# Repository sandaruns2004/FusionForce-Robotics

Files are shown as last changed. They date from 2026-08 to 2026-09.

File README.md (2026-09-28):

# FusionForce RUNNER-4 — BREACH PROTOCOL
## EN2533 Autonomous Quadruped Competition Robot

> **MCU:** STM32F411CEU6 (Black Pill) | **Servos:** 15× MG90S | **Links:** L1=30mm L2=60mm L3=80mm
> **Gait:** Diagonal Trot | **Sensors:** 9-ch IR (ADC DMA) + 3× ToF + IMU + Colour

A fully autonomous 12-DOF 3D-printed quadruped robot built for the EN2533 BREACH PROTOCOL competition. All perception, mission logic, and real-time motor control run on a **single STM32F411CEU6** — no Raspberry Pi, no computer vision, no external processor.

---

## 🗂️ Repository Structure

```
FusionForce-Robotics/
├── docs/                   ← Engineering documentation (start here)
├── firmware/               ← STM32F411CEU6 bare-metal C firmware
├── Mechanical/             ← 3D print guides, assembly, calibration
├── Robot_Curriculum/       ← Learning path: L1 Fundamentals → L4 Sensors & Integration
├── Testing codes/          ← Arduino/STM32 test scripts per subsystem
├── 3D designs/             ← SolidWorks CAD assemblies
├── Task/                   ← Arena task specifications
└── Proposal/               ← Competition proposal documents
```

---

## ⚡ System at a Glance

```
         9× TCRT5000 IR Array    3× VL53L0X ToF    MPU6050    TCS34725
         (ADC1+DMA PA0-PA7,PB0)  (I2C2, XSHUT)    (I2C1)    (I2C1, arm tip)
                  │                    │               │           │
         ┌────────┴────────────────────┴───────────────┴───────────┴────────┐
         │              STM32F411CEU6 Black Pill (100MHz)                    │
         │  Mission HFSM (21 states) │ Trot Gait (600ms) │ IK Solver       │
         │  PD Line Follow │ PD Wall Follow │ Flash persistence │ UART debug│
         └───────────────────────────────┬────────────────────────────────── ┘
                                         │ I2C1 (400kHz)
                                   PCA9685 (0x40)
                                         │
              ┌──────────────┬───────────┴───────────┬──────────────┐
         CH0-CH11        CH12 Arm           CH13 Gripper      CH14 Gate
         12× MG90S       MG90S (0-160°)     MG90S (60-115°)  MG90S (0-90°)
         Leg Servos
```

---

## 🦾 Hardware Specification

| Parameter | Value |
|---|---|
| **MCU** | STM32F411CEU6 Black Pill — 100MHz ARM Cortex-M4F, FPU |
| **Servos** | 15× MG90S metal-gear, 2.2 kg·cm @ 6V |
| **Leg DOF** | 12 (3-DOF per leg × 4 legs) |
| **Coxa (L1)** | **30 mm** |
| **Femur (L2)** | **60 mm** |
| **Tibia (L3)** | **80 mm** |
| **Max reach** | L2+L3 = **140 mm** from coxa pivot |
| **Gait** | Diagonal trot — FL+BR / FR+BL, T=600ms, step=35mm |
| **Servo driver** | PCA9685, I2C1 (0x40), 50Hz, 500-2400µs |
| **Line array** | 9× TCRT5000, ADC1+DMA, 80mm wide, 10mm pitch |
| **ToF sensors** | 3× VL53L0X, I2C2 (0x30/0x31/0x32), XSHUT remapped |
| **IMU** | MPU6050, I2C1 (0x68), 100Hz, tilt safety watchdog |
| **Colour sensor** | TCS34725, I2C1 (0x29), arm tip mount, LED=PC0 |
| **Power** | 2S LiPo → 6V BEC (servo) + 3.3V logic, star ground |
| **Chassis** | PETG 3D-printed, body 160×120mm |

---

## 📚 Documentation

👉 **[Full Engineering Docs →](docs/README.md)**

| Doc | Description |
|-----|---|
| [Technical Blueprint](docs/TECHNICAL_BLUEPRINT.md) | Complete system manual — start here |
| [Hardware Architecture](docs/HARDWARE_ARCHITECTURE.md) | Compute, sensor, actuator block diagram |
| [Pinout & Connections](docs/PINOUT_AND_CONNECTIONS.md) | Authoritative STM32 pin assignment table |
| [Locomotion & Kinematics](docs/LOCOMOTION_AND_KINEMATICS.md) | IK derivation, trot gait math, PD controllers |
| [Embedded State Machine](docs/EMBEDDED_STATE_MACHINE.md) | 21-state HFSM — all 4 competition tasks |
| [Sensor Perception](docs/SENSOR_PERCEPTION.md) | 9-ch IR array + TCS34725 algorithms |
| [Software Architecture](docs/SOFTWARE_ARCHITECTURE.md) | Firmware structure, 50Hz loop |
| [Power Architecture](docs/POWER_ARCHITECTURE.md) | Dual-rail power, star ground, protection |
| [Mechanical Design](docs/MECHANICAL_DESIGN.md) | Chassis, leg assembly, arm, CoM analysis |
| [Troubleshooting Guide](docs/TROUBLESHOOTING.md) | UART debug commands, common fixes |
| [Master Checklist](docs/MASTER_IMPLEMENTATION_CHECKLIST.md) | Step-by-step build + test checklist |

---

## 🎓 Team Learning Curriculum

New team members: complete the curriculum before touching firmware code.

👉 **[Master Robotics Curriculum →](Robot_Curriculum/README.md)**

| Level | Topics | Est. Time |
|---|---|---|
| [Level 1 — Fundamentals](Robot_Curriculum/Level_1_Fundamentals/README.md) | C, Electronics, Git, CubeMX setup | 2–3 weeks |
| [Level 2 — STM32](Robot_Curriculum/Level_2_STM32/README.md) | HAL, I2C, ADC DMA, PCA9685, Timers | 2–3 weeks |
| [Level 3 — Robotics Core](Robot_Curriculum/Level_3_Robotics/README.md) | IK, trot gait, PD control, HFSM | 2–3 weeks |
| [Level 4 — Sensors & Integration](Robot_Curriculum/Level_4_Sensors_and_Gait/README.md) | Full mission, all sensors, competition run | 1–2 weeks |

---

## 🔧 Mechanical Assembly

👉 **[Mechanical Assembly Workflow →](Mechanical/README.md)**

| Module | Description |
|---|---|
| [01 Chassis Design](Mechanical/01_chassis_design/README.md) | PETG print specs, CoG planning |
| [02 Leg Assembly](Mechanical/02_leg_assembly/README.md) | 12× MG90S, L1/L2/L3 links, channel map |
| [03 Gripper & Gate](Mechanical/03_gripper_and_bumper/README.md) | CH12 arm, CH13 gripper, CH14 gate |
| [04 Electronics Mounting](Mechanical/04_electronics_mounting/README.md) | STM32, PCA9685, all sensor placements |
| [05 Power Distribution](Mechanical/05_power_distribution/README.md) | 6V servo rail, 3.3V logic, star ground |
| [06 Calibration & Zeroing](Mechanical/06_calibration_and_zeroing/README.md) | 15-servo zeroing, UART calibration |
| [07 Maintenance & Repair](Mechanical/07_maintenance_and_repair/README.md) | Pre-run checklist, failure diagnosis |

---

## 🏁 Competition Tasks

| Task | Description | Primary Sensors |
|---|---|---|
| **Task 1** | Follow white line → find ball → colour ID → grab & store | IR array (line) + ToF (proximity) + TCS34725 (colour) |
| **Task 2** | Navigate corridor with gaps | ToF ×3 (wall-follow PD) |
| **Task 3** | Detect and push obstacle | ToF front (obstacle) + IMU (tilt safety) |
| **Task 4** | Follow line → junction → colour-match zone → release ball | IR array + TCS34725 (floor zone) |

---

*Repository status: Active development. All documentation is current as of hardware confirmation: L1=30mm, L2=60mm, L3=80mm, 15× MG90S, STM32F411CEU6.*

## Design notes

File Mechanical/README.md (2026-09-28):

# Mechanical Assembly & Hardware Workflow
## RUNNER-4 | 12-DOF Quadruped | EN2533 BREACH PROTOCOL

> **MCU:** STM32F411CEU6 (Black Pill) | **Servos:** 12x MG90S legs + 3x MG90S mechanisms = **15 total**
> **Links:** Coxa = 30 mm | Femur = 60 mm | Tibia = 80 mm | **Power:** 6V switching BEC ≥5A

## Assembly Workflow

```mermaid
flowchart TD
    classDef phase fill:#1a3a5c,stroke:#2e86de,color:#fff,stroke-width:2px;
    classDef critical fill:#7b1e1e,stroke:#e74c3c,color:#fff,stroke-width:2px;

    A[01. Chassis Design\n3D Print + Materials + CoG]:::phase
    B[02. Leg Assembly\n12x MG90S + 3-DOF per leg]:::phase
    C[03. Gripper + Gate\nCH12 Arm + CH13 Grip + CH14 Gate]:::phase
    D[04. Electronics Mounting\nSTM32 + PCA9685 + Sensors]:::phase
    E[05. Power Distribution\n6V BEC + 3.3V Logic Rail]:::phase
    F[06. Servo Zeroing\n90-deg Mechanical Calibration]:::critical
    G[07. Maintenance\nPre-Run Checklists]:::phase

    A --> B
    B --> C
    C --> D
    D --> E
    E --> F
    F --> G
```

## Module Summary

| # | Module | Key Hardware | Status |
|---|---|---|---|
| 01 | [Chassis Design](./01_chassis_design/README.md) | PETG body, base plate, top plate | Design phase |
| 02 | [Leg Assembly](./02_leg_assembly/README.md) | 12x MG90S, L1=30 L2=60 L3=80mm | Assembly phase |
| 03 | [Gripper & Gate](./03_gripper_and_bumper/README.md) | CH12 arm, CH13 gripper, CH14 gate | Assembly phase |
| 04 | [Electronics Mounting](./04_electronics_mounting/README.md) | STM32, PCA9685, IMU, ToF, IR array | Wiring phase |
| 05 | [Power Distribution](./05_power_distribution/README.md) | Switching BEC 6V, 3.3V logic | Wiring phase |
| 06 | [Calibration & Zeroing](./06_calibration_and_zeroing/README.md) | PCA9685 UART cal, offset array | **Critical step** |
| 07 | [Maintenance & Repair](./07_maintenance_and_repair/README.md) | Pre-run checklist, common failures | Ongoing |

## Hardware Bill of Materials (Mechanical)

| Item | Qty | Spec | Notes |
|---|-----|---|---|
| MG90S Metal Gear Servo | 15 | 2.2 kg.cm @ 6V | 12 legs + 3 arm/grip/gate |
| PETG Filament | ~400g | 1.75mm, black | Body plates + brackets |
| M3 Socket Head Screws | 80 | 8mm, 12mm, 16mm | All structural joints |
| M3 Locknuts (nylon) | 60 | DIN985 | Vibration-proof joints |
| M2.5 Standoffs | 20 | Brass, 10mm | PCB mounting |
| Brass Heat-set Inserts | 40 | M3 | PETG structural holes |
| Radial Bearings | 12 | 3x8x3mm MR83ZZ | Opposite side of coxa servo horns |
| Rubber Feet | 4 | 10mm dia silicone | Tibia tips, prevents slipping |
| Servo Extension Wire | 2m | 3-pin 26AWG | Leg routing |

---
🔙 **[Back to Main Repository README](../README.md)**

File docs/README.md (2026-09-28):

# FusionForce Engineering Documentation
## RUNNER-4 | EN2533 BREACH PROTOCOL | STM32F411CEU6

Authoritative technical documentation, architectural blueprints, and tracking checklists.
**No Raspberry Pi. No Computer Vision. All perception is sensor-based (IR array, ToF, colour sensor, IMU).**

## Core Planning & Tracking

| Document | Purpose |
|---|---|
| **[Technical Blueprint](./TECHNICAL_BLUEPRINT.md)** | Comprehensive system manual — Start Here |
| **[Technical Proposal](./TECHNICAL_PROPOSAL.md)** | Executive engineering proposal |
| **[Execution Report](./EXECUTION_REPORT.md)** | Project management tracker |
| **[Master Implementation Checklist](./MASTER_IMPLEMENTATION_CHECKLIST.md)** | Step-by-step implementation guide |
| **[Risk Register (FMEA)](./RISK_REGISTER.md)** | Risk analysis and mitigation |
| **[Requirements](./REQUIREMENTS.md)** | System requirements and constraints |

## Technical Architecture

| Document | Purpose |
|---|---|
| **[System Overview](./SYSTEM_OVERVIEW.md)** | Single-domain STM32 architecture — why no Raspberry Pi |
| **[Hardware Architecture](./HARDWARE_ARCHITECTURE.md)** | Compute + sensor + actuator layers, block diagram |
| **[STM32 Architecture](./STM32_ARCHITECTURE.md)** | STM32F411CEU6 peripherals, CubeMX config |
| **[Software Architecture](./SOFTWARE_ARCHITECTURE.md)** | 50Hz loop, firmware directory structure |
| **[Power Architecture](./POWER_ARCHITECTURE.md)** | 6V servo rail, 3.3V logic rail, star ground |
| **[Locomotion & Kinematics](./LOCOMOTION_AND_KINEMATICS.md)** | IK solver (L1=30 L2=60 L3=80mm), trot gait, PD controllers |
| **[Mechanical Design](./MECHANICAL_DESIGN.md)** | PETG chassis, leg assembly, arm+gripper, line array bracket |
| **[Embedded State Machine](./EMBEDDED_STATE_MACHINE.md)** | 21-state HFSM, all 4 tasks, transition tables |

## Sensors & Perception

| Document | Purpose |
|---|---|
| **[Sensor Perception](./SENSOR_PERCEPTION.md)** | 9-ch IR array (ADC DMA) + TCS34725 algorithms |
| **[Pinout and Connections](./PINOUT_AND_CONNECTIONS.md)** | Complete STM32 pin assignments (authoritative) |

## Safety & Maintenance

| Document | Purpose |
|---|---|
| **[Safety and Failure Modes](./SAFETY_AND_FAILURE_MODES.md)** | Failsafes, hardware protection, SAFE_STOP |
| **[Troubleshooting Guide](./TROUBLESHOOTING.md)** | Common issues, UART debug commands, fixes |

## Quick Reference

### Hardware at a Glance
```
MCU:    STM32F411CEU6 Black Pill — 100MHz, 512KB Flash, 128KB RAM
Servos: 15× MG90S | CH0-11 legs | CH12 arm | CH13 gripper | CH14 gate
Links:  L1 (Coxa)=30mm | L2 (Femur)=60mm | L3 (Tibia)=80mm
Gait:   Trot | T=600ms | Step height=35mm | Vx_max=100mm/s
Power:  6V BEC (servo) | 3.3V logic | 2S LiPo | Star ground
```

### I2C Bus Map
```
I2C1 (PB6/PB7): PCA9685@0x40 | MPU6050@0x68 | TCS34725@0x29
I2C2 (PB10/PB3): VL53L0X Front@0x30 | Left@0x31 | Right@0x32
```

### ADC Line Array
```
ADC1 + DMA1 circular | S1-S8: PA0-PA7 | S9: PB0
9× TCRT5000 | 80mm wide | 10mm pitch | 16× oversample | 5mm from floor
Centroid range: 0-8 | error = centroid - 4.0
```

### Arm Positions
```
CH12 HOME  = 90°  (tick 307) — vertical, safe for walking
CH12 MODE_A = 0°  (tick 102) — horizontal forward, ball at pedestal
CH12 MODE_B = 160° (tick 450) — angled down to floor, zone ID
CH13 OPEN   = 60°  (tick 184) — gripper open (40mm ball)
CH13 CLOSE  = 115° (tick 286) — gripper gripping
CH14 LOCKED = 0°   (tick 102) — gate closed
CH14 OPEN   = 90°  (tick 307) — gate open (ball exits)
```

---
🔙 **[Back to Main Repository README](../README.md)**

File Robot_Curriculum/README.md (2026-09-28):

# FusionForce Master Robotics Curriculum
## RUNNER-4 | EN2533 BREACH PROTOCOL | STM32F411CEU6

Progress through these 4 levels to build full competency for autonomous quadruped development.
No computer vision — all perception is sensor-based (IR array, ToF, colour sensor, IMU).

## Curriculum Path

```mermaid
flowchart LR
    L1["Level 1\nFundamentals\nC + Electronics\nGit + Linux"]
    L2["Level 2\nSTM32 Firmware\nHAL + I2C + ADC\nDMA + Timers"]
    L3["Level 3\nRobotics Core\nIK + Gait\nPID + State Machine"]
    L4["Level 4\nSensors & Gait\nFull Integration\nCompetition Ready"]
    L1 --> L2 --> L3 --> L4
```

## Modules

| Level | Module | Topics | Time Estimate |
|---|---|---|---|
| [Level 1](./Level_1_Fundamentals/README.md) | Fundamentals | C, Electronics, Git, STM32 setup | 2–3 weeks |
| [Level 2](./Level_2_STM32/README.md) | STM32 Firmware | HAL, I2C, ADC DMA, PCA9685, Timers | 2–3 weeks |
| [Level 3](./Level_3_Robotics/README.md) | Robotics Core | IK solver, trot gait, PD control | 2–3 weeks |
| [Level 4](./Level_4_Sensors_and_Gait/README.md) | Sensors & Integration | All sensors, HFSM, full mission | 1–2 weeks |

## What This Curriculum Does NOT Cover
- Computer vision / OpenCV — all RUNNER-4 perception uses hardware sensors
- Raspberry Pi — all logic runs on STM32F411CEU6
- ROS / ROS2 — bare-metal HAL only

---
🔙 **[Back to Main Repository README](../README.md)**

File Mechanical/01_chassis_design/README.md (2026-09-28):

# 01 Chassis Design
## RUNNER-4 | Body Frame and 3D Printing Guide

## Objective
Design and 3D-print a rigid, perfectly symmetrical chassis that keeps the Center of Gravity (CoG) within the quadruped's support polygon at all times.

## Body Dimensions

```
Top view:

  FL coxa mount ----+--------+---- FR coxa mount
                    |        |
                    | BODY   |
                    | 160mm  |
                    | x      |
                    | 120mm  |
                    |        |
  BL coxa mount ----+--------+---- BR coxa mount

  Body half-length (front/rear to centre): 80 mm
  Body half-width  (left/right to centre): 60 mm
  CoG target: geometric centre of body plate
```

## 3D Printing Specifications

| Part | Material | Infill | Perimeters | Notes |
|---|---|---|---|---|
| Base plate (bottom deck) | PETG | 40% Gyroid | 4 | Battery + BEC mounting surface |
| Top plate (upper deck) | PETG | 30% Gyroid | 4 | STM32 + PCA9685 mounting surface |
| Coxa servo bracket (x4) | PETG | 100% | 5 | Highest stress — no PLA |
| Femur link (x4) | PETG | 50% Gyroid | 4 | |
| Tibia link (x4) | PETG | 50% Gyroid | 4 | Rubber foot socket at tip |
| Arm mount bracket | PETG | 100% | 4 | CH12 arm pitch servo mount |
| Gripper fingers (x2) | PETG/TPU | 80% | 3 | TPU preferred — better grip |
| Gate plate | PETG | 60% | 3 | CH14 gate servo horn mount |

> **Do NOT use PLA** for structural parts. PLA deforms under continuous servo heat (>55°C body temperature) and shatters on arena collision impacts.

## Slicer Settings (Cura / PrusaSlicer)

```
Layer height:     0.2mm standard | 0.15mm for servo brackets
Print speed:      40mm/s perimeters | 60mm/s infill
Bed temp:         80°C (PETG)
Nozzle temp:      240°C (PETG)
Supports:         Only for overhangs > 50°
Cooling:          Moderate (PETG warps with aggressive cooling)
```

## Center of Gravity Planning

The quadruped's support polygon during trot gait is the diagonal between FL+BR or FR+BL. The CoG must stay inside this triangle at all times:

```
  CoG position targets:
  - Battery (heaviest, ~200g): centre of bottom deck, LOW
  - PCA9685 + STM32: middle deck, centred front-back
  - Sensors (ToF/IMU): front of top deck, symmetric

  AVOID: mounting heavy components at back edge
  (shifts CoG backward -> front legs lose traction on acceleration)
```

## Assembly Tasks

1. Export all STLs from the `3D designs/` folder (SolidWorks assemblies)
2. Slice with PETG profiles above
3. Install M3 brass heat-set inserts into all screw holes (use soldering iron tip at 200°C)
4. Print 4x coxa brackets — test-fit servo before installing inserts
5. Assemble base plate + standoffs for middle deck
6. Assemble top deck plate

## Files Location
- CAD sources: [`3D designs/`](../3D%20designs/)
- Reference assembly: `3D designs/` SolidWorks files

---
🔙 **[Back to Mechanical](../README.md)**

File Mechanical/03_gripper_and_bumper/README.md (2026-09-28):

# 03 Gripper & Gate Mechanism
## RUNNER-4 | CH12 Arm Pitch | CH13 Gripper | CH14 Gate

## Objective
Build the three mechanism servos that handle ball retrieval (Task 1), storage, and ball release into the colour-sorted zone (Task 4).

## Mechanism Overview

```
  SIDE VIEW OF ROBOT:

  HOME (CH12 = 90°):           ARM pointing UP — safe for travel/walk

  MODE_A (CH12 = 0°):          ARM horizontal FORWARD
                                Sensor at ball height (~5cm above pedestal)
                                Use for: Task 1 ball approach + colour ID

  MODE_B (CH12 = 160°):        ARM angled DOWN to floor
                                Sensor 2cm above floor zone
                                Use for: Task 4 zone colour identification

  Gripper CH13:
    OPEN  = 60°  → fingers wider than 40mm ball diameter
    CLOSE = 115° → fingers grip ball firmly

  Gate CH14 (belly storage door):
    LOCKED = 0°  → plate closed, retains ball inside body
    OPEN   = 90° → plate rotates, ball rolls out into zone
```

## PCA9685 Channels — Mechanism Servos

| CH | Function | Servo | HOME tick | Key positions |
|----|---|---|---|---|
| 12 | Arm pitch | MG90S | 307 (90°) | 102=MODE_A(0°), 450=MODE_B(160°), 380=STORE(135°) |
| 13 | Gripper | MG90S | 184 (60°) | 184=OPEN(60°), 286=CLOSE(115°) |
| 14 | Gate | MG90S | 102 (0°) | 102=LOCKED(0°), 307=OPEN(90°) |

## Torque Budget

| Servo | Load | Required | MG90S @ 6V | Margin |
|---|---|---|---|---|
| CH12 Arm | 40mm ball at 65mm arm | 2.35 kg·cm | 2.2 kg·cm | **0.94x — marginal** |
| CH13 Gripper | Ball grip force | 1.02 kg·cm | 2.2 kg·cm | 2.15x OK |
| CH14 Gate | Spring-loaded door | 0.76 kg·cm | 2.2 kg·cm | 2.89x OK |

> **⚠️ CH12 Arm Warning:** Torque margin is below 1.0x at maximum arm extension.
> Fix options: (A) Shorten arm link to 55mm, (B) Upgrade CH12 to MG996R (10 kg·cm), (C) Add counterweight.

## Hardware Required

| Part | Qty | Notes |
|---|-----|---|
| MG90S metal-gear servo | 3 | CH12, CH13, CH14 |
| Arm link (PETG, 100% infill) | 1 | 65mm long, servo horn mount one end, TCS34725 mount other end |
| Gripper fingers (PETG or TPU) | 2 | Line with rubber band or foam tape for friction |
| Gate plate (PETG, 60% infill) | 1 | Hinged to belly of chassis |
| M3×8 screws | 8 | Servo mounting |
| M2 screws | 4 | TCS34725 sensor mount on arm tip |

## TCS34725 Colour Sensor on Arm

The TCS34725 colour sensor mounts at the **tip of the arm link**:
- ARM_MODE_A (0°): sensor faces ball at pedestal height → identifies ball colour
- ARM_MODE_B (160°): sensor faces floor zone → identifies floor zone colour for Task 4

```
  Arm tip wiring:
  TCS34725 -> I2C1 bus (SDA=PB7, SCL=PB6) shared with MPU6050
  LED control -> PC0 (GPIO output, HIGH = white LED ON for measurement)
  I2C address: 0x29
```

## Sequence per Task

### Task 1 — Ball Retrieval
```
1. SM: T1_LINE_FOLLOW  -> ARM_HOME,  GRIPPER_OPEN,  GATE_LOCKED
2. SM: T1_BALL_APPROACH-> ARM_MODE_A, GRIPPER_OPEN,  GATE_LOCKED  (800ms)
3. SM: T1_COLOR_ID     -> ARM_MODE_A, GRIPPER_OPEN,  GATE_LOCKED  (3 stable reads)
4. SM: T1_BALL_GRAB    -> ARM_MODE_A, GRIPPER_CLOSE, GATE_LOCKED  (1200ms)
5. SM: T1_STORE        -> ARM_HOME,   GRIPPER_CLOSE, GATE_LOCKED  (1000ms)
```

### Task 4 — Ball Release
```
6. SM: T4_JUNCTION     -> ARM_MODE_B, GRIPPER_CLOSE, GATE_LOCKED  (floor zone ID)
7. SM: T4_BALL_RELEASE -> ARM_HOME,   GRIPPER_OPEN,  GATE_OPEN    (1500ms, ball exits)
```

## Assembly Steps

1. Mount CH12 arm servo to chassis front face, servo shaft pointing UP
2. Attach arm link to servo horn (do NOT attach horn until Module 06 zeroing)
3. Mount TCS34725 PCB to arm tip with M2 screws, LED facing outward
4. Route TCS34725 I2C cable along arm, secure with small zip ties at 10mm intervals — must not snag during arm movement
5. Mount CH13 gripper servo to arm link midpoint
6. Attach finger assembly to CH13 servo horn
7. Line finger interior with 2mm foam tape or rubber band strips
8. Mount gate plate hinge to belly chassis with M3×16 bolts
9. Attach CH14 gate servo to chassis side, servo horn attached to gate plate
10. Verify gate: at 0° plate fully closes, at 90° plate swings clear (ball can exit)

## Debugging

| Problem | Cause | Fix |
|---|---|-----|
| Arm droops under ball weight | CH12 margin too low | Shorten arm link or upgrade to MG996R |
| Gripper can't hold ball | Fingers too smooth | Add rubber band / foam tape lining |
| Gate doesn't open fully | Servo horn angle wrong | Re-zero CH14 at Module 06 |
| Colour reads wrong at MODE_A | LED (PC0) not powered | Verify PC0 GPIO HIGH before reading |
| Arm cable snags during walk | Cable too short/loose | Add 50mm slack loop, zip-tie to chassis |

---
🔙 **[Back to Mechanical](../README.md)**

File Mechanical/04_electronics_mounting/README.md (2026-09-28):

# 04 Electronics Mounting
## RUNNER-4 | STM32F411CEU6 + PCA9685 + Sensor Suite

## Objective
Securely mount all electronics to withstand continuous walking vibrations and ensure correct sensor field-of-view (FoV) placement.

## Electronics Stack Layout

```
  TOP DECK (upper plate):
  ┌─────────────────────────────────────────┐
  │  STM32F411CEU6 Black Pill               │  <- Screwed into M2.5 brass standoffs
  │  (on perfboard/custom PCB)              │
  │                                         │
  │  PCA9685 PWM Driver (0x40)              │  <- Screwed into M2.5 standoffs
  │  [4.7kΩ pull-ups I2C1 SDA/SCL]         │
  └─────────────────────────────────────────┘

  SENSOR POSITIONS (top deck, front face):
  ┌─────────────────────────────────────────┐
  │  [VL53L0X LEFT]  [VL53L0X FRONT]  [VL53L0X RIGHT]  │
  │  addr 0x31        addr 0x30         addr 0x32       │
  │  XSHUT PB13       XSHUT PB12       XSHUT PB14      │
  │                                                     │
  │  [MPU6050 IMU] — mount at geometric centre, flat    │
  │  addr 0x68  I2C1                                    │
  └─────────────────────────────────────────┘

  BOTTOM DECK (base plate):
  ┌─────────────────────────────────────────┐
  │  LiPo Battery 2S/3S        (Velcro strap, centre)  │
  │  Switching BEC 6V ≥5A      (Zip-tie side mount)    │
  │  3.3V LDO/SMPS             (Side mount)            │
  └─────────────────────────────────────────┘

  FRONT EDGE (IR sensor bar):
  ┌─────────────────────────────────────────┐
  │  9x TCRT5000 IR sensors (S1-S9)         │
  │  PA0-PA7, PB0 → ADC1 DMA               │
  │  Mounted 5mm above arena floor          │
  │  80mm total width, 10mm pitch           │
  └─────────────────────────────────────────┘
```

## Component List

| Component | Mount Location | Mount Method | Notes |
|---|---|---|---|
| STM32F411CEU6 | Top deck | M2.5 nylon standoffs + rubber washers | Vibration isolation |
| PCA9685 | Top deck | M2.5 brass standoffs | Keep away from IR sensors |
| MPU6050 IMU | Top deck, geometric centre | M2.5 standoffs, perfectly flat | ±1° tilt tolerance |
| TCS34725 Colour Sensor | Arm tip (CH12) | M2 screws | Moves with arm |
| VL53L0X Front | Front edge, centre | M2 mount, forward-facing | 0° horizontal |
| VL53L0X Left | Left edge | M2 mount, 90° left-facing | Exactly perpendicular |
| VL53L0X Right | Right edge | M2 mount, 90° right-facing | Exactly perpendicular |
| 9x TCRT5000 IR | Underside front bar | Custom PCB / perfboard | 5mm from floor |
| Switching BEC | Bottom deck | Zip-tie | 6V servo power |
| LiPo Battery | Bottom deck centre | Velcro strap | CoG alignment critical |

## I2C Bus Wiring

```
I2C1 (SDA=PB7, SCL=PB6) — 4.7kΩ pull-ups to 3.3V:
  PCA9685      @ 0x40   (PWM driver, 15 servos)
  MPU6050      @ 0x68   (IMU)
  TCS34725     @ 0x29   (colour sensor on arm)

I2C2 (SDA=PB3, SCL=PB10) — 4.7kΩ pull-ups to 3.3V:
  VL53L0X Front @ 0x30  (remapped from 0x29 via XSHUT PB12)
  VL53L0X Left  @ 0x31  (remapped from 0x29 via XSHUT PB13)
  VL53L0X Right @ 0x32  (remapped from 0x29 via XSHUT PB14)
```

> **Why separate I2C buses?** VL53L0X readings take ~30ms each. If on I2C1 with PCA9685, ToF measurements would block servo updates. I2C2 isolates them completely.

## ADC / DMA Wiring

```
ADC1 + DMA1 (circular scan, 16x oversampling):
  S1 PA0   S2 PA1   S3 PA2   S4 PA3   S5 PA4
  S6 PA5   S7 PA6   S8 PA7   S9 PB0

  Pull-up resistors: 10kΩ to 3.3V for each TCRT5000 emitter
  DMA buffer: 9 × 16 = 144 uint32_t words
```

## GPIO Assignments

| Pin | Function | Direction | Notes |
|-----|---|---|---|
| PB12 | VL53L0X FRONT XSHUT | Output PP | LOW=reset, HIGH=active |
| PB13 | VL53L0X LEFT XSHUT | Output PP | |
| PB14 | VL53L0X RIGHT XSHUT | Output PP | |
| PC0 | TCS34725 LED enable | Output PP | HIGH=LED ON |
| PC13 | Start button | Input PU | Active LOW (press to start) |
| PA9 | USART1 TX | Alt AF7 | Debug 115200 baud |
| PA10 | USART1 RX | Alt AF7 | |

## Sensor Placement Rules

### MPU6050 IMU (CRITICAL)
- Must be at **exact geometric centre** of robot body
- Must be **perfectly horizontal** (±1° tolerance)
- If tilted, the complementary filter will report false pitch/roll and the state machine will trigger `IMU_TIP_THRESHOLD` incorrectly
- Mount with rubber washers to dampen servo vibration from IMU accelerometer

### VL53L0X ToF Sensors
- Front sensor: pointing **dead ahead**, 0° from robot X-axis
- Left sensor: pointing **exactly 90° left**, perpendicular to robot Y-axis
- Right sensor: pointing **exactly 90° right**
- No chassis parts in the 25° cone FoV — check by shining a torch through the FoV
- Sensors mounted at **same height** as corridor wall mid-height (approx. 40mm from floor)

### IR Line Array (9x TCRT5000)
- Mounted **5mm above arena floor** — optimal TCRT5000 sensing distance
- Total width: 80mm, pitch: 10mm between sensors (S1-S9 left to right)
- S5 (PA4, centre) must align with robot X-axis centreline
- Sensor PCB must be rigid — flex PCB causes variable readings

## Vibration Mitigation

- Use **nylon M2.5 standoffs** + rubber washers for all PCB mounts
- Apply **hot glue** or cable tie to all I2C/power connector joints (arena vibrations loosen DuPont connectors)
- Route servo cables along structural members, not free-hanging

---
🔙 **[Back to Mechanical](../README.md)**

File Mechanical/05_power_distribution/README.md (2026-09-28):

# 05 Power Distribution
## RUNNER-4 | Dual-Rail Power System | 6V Servo + 3.3V Logic

## Objective
Route high-current servo power and low-noise logic power safely, avoiding brownouts, ground loops, and servo damage to the STM32.

## The Two Power Rails

```
  LiPo Battery (2S=7.4V or 3S=11.1V)
       |
       +---[Kill Switch 15A]---+
                               |
               +---------------+---------------+
               |                               |
   [Switching BEC ≥5A]               [LDO/SMPS 3.3V]
   Output: 6.0V                      Output: 3.3V
               |                               |
   +-----------+----------+         +----------+-----------+
   |           |          |         |          |           |
  PCA9685   Servo V+   Servo V+   STM32    PCA9685   Sensors
  (servo)   CH0-CH11  CH12-14    VCC       (logic)  (I2C/ADC)

  GND: ALL above share one thick common GND wire (star ground)
```

## Power Consumption Analysis

| Component | Rail | Typical | Peak (stall) |
|---|---|---|---|
| STM32F411CEU6 | 3.3V | 30 mA | 50 mA |
| PCA9685 logic | 3.3V | 10 mA | 15 mA |
| MPU6050 | 3.3V | 3.9 mA | 4 mA |
| TCS34725 + LED | 3.3V | 11 mA | 11 mA |
| 3× VL53L0X | 3.3V | 30 mA | 30 mA |
| 9× TCRT5000 IR | 3.3V | 81 mA | 81 mA |
| **3.3V Total** | | **~166 mA** | ~191 mA |
| 12× MG90S legs | 6V | 1200–2400 mA | 8400 mA |
| 3× MG90S arm/grip/gate | 6V | 200–400 mA | 2100 mA |
| **6V Servo Total** | | **1.4–2.8 A** | **~10.5 A stall** |

> **BEC Selection:** Must be switching type, ≥5A continuous, ≥10A peak. Linear BEC overheats and causes brownout at high current. Recommended: 5A or 8A SBEC module.

## Wiring Steps

### Step 1: Battery and Kill Switch
```
1. Solder XT60 male connector to LiPo leads
2. Splice 15A latching toggle switch onto RED (positive) lead
   - Switch in series, NOT across the battery
3. Add 10A automotive blade fuse inline to servo BEC output
```

### Step 2: 6V Servo Rail (BEC)
```
1. Connect BEC input (raw) to battery positive rail
2. Set BEC output to 6.0V ± 0.1V (measure with multimeter under load)
3. Connect BEC output (+6V) to PCA9685 V+ terminal block
4. DO NOT connect BEC output to PCA9685 VCC pin (that is logic power only)
5. All 15 servo red wires connect to the same +6V rail
```

### Step 3: 3.3V Logic Rail
```
1. Connect LDO/SMPS input to battery positive rail
2. Set output to 3.3V ± 0.05V
3. Connect to STM32 3V3 pin
4. Connect to PCA9685 VCC (logic)
5. Connect to all sensor VCC pins (MPU6050, VL53L0X ×3, TCS34725)
   NOTE: TCRT5000 IR sensors — use 3.3V with 10kΩ pull-up resistors
```

### Step 4: Star Ground
```
ALL of the following GND wires must join at ONE point:
  - BEC output GND
  - LDO/SMPS output GND
  - STM32 GND pin
  - PCA9685 GND (both logic GND and servo GND rails)
  - All sensor GND pins
  - LiPo battery negative

Use a thick (18AWG) wire from LiPo negative to this star point.
From star point use thinner wires to individual components.
This eliminates ground loops that cause servo jitter and IMU noise.
```

## Pull-up Resistors (I2C)

```
I2C1 (PB6 SCL, PB7 SDA): 4.7kΩ to 3.3V (×2 resistors)
I2C2 (PB10 SCL, PB3 SDA): 4.7kΩ to 3.3V (×2 resistors)
Total: 4 resistors (4.7kΩ 0603 or through-hole)
```

> **Never omit pull-ups.** Without them, I2C signals float and all I2C devices (PCA9685, MPU6050, VL53L0X, TCS34725) will fail intermittently.

## Safety Features

| Protection | Component | Spec | Purpose |
|---|---|---|---|
| Main fuse | Automotive blade | 15A | Protects battery leads |
| Servo fuse | Automotive blade | 10A | Protects BEC output |
| Kill switch | Latching toggle | 15A | Emergency off |
| Decoupling caps | Ceramic 100nF | X7R | One per sensor/IC for noise |
| Servo rail cap | Electrolytic 470µF | 16V | Absorbs servo current spikes |

## Voltage Checks (before first power-on)

```
[ ] Battery voltage > 7.4V (2S) or > 11.1V (3S)
[ ] BEC output = 6.0V ± 0.1V  (under servo load)
[ ] 3.3V rail  = 3.30V ± 0.05V
[ ] All sensor VCC pins read 3.3V
[ ] PCA9685 V+  reads 6.0V
[ ] PCA9685 VCC reads 3.3V
[ ] All GND connections continuity-checked
[ ] No short between 6V rail and 3.3V rail
```

## Common Mistakes

| Mistake | Consequence | Fix |
|---|---|-----|
| Servo wire into STM32 5V/3.3V pin | STM32 burned instantly | Use BEC output only |
| Linear BEC at high servo current | Overheating, brownout | Use switching BEC only |
| Missing star ground | Ground loops, servo jitter, IMU noise | Wire all GNDs together |
| Missing I2C pull-ups | I2C bus failure, all sensors fail | Add 4.7kΩ per bus |
| Missing servo rail cap | Servo spike brownouts | Add 470µF on servo rail |

---
🔙 **[Back to Mechanical](../README.md)**

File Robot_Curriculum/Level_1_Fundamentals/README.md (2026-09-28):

# Level 1 — Fundamentals
## Prerequisites for RUNNER-4 Firmware Development

## Why This Level Matters
Every higher-level skill (IK math, gait engines, sensor drivers) depends on these fundamentals. Gaps here cause mysterious bugs later. Invest the time.

## Topics

### 1. C Programming for Embedded Systems
| Topic | Key Concepts | Application on RUNNER-4 |
|---|---|---|
| Pointers & memory | `*ptr`, `&addr`, arrays as pointers | IK solver passes `FootTarget_t *foot` |
| Structs | `typedef struct { float x,y,z; } FootTarget_t` | All data passed as structs |
| Fixed-width types | `uint8_t`, `uint16_t`, `int16_t` | ADC buffers, I2C register maps |
| Bitwise operations | `&`, `\|`, `<<`, `>>` | PCA9685 register config, ADC status |
| `volatile` keyword | Prevents compiler optimisation of ISR variables | `volatile uint8_t update_flag` in main loop |
| `const` arrays | Read-only flash data | `IK_NeutralStance[4]`, calibration tables |
| Math.h | `atan2f()`, `sqrtf()`, `sinf()`, `acosf()` | Entire IK + gait engine |

### 2. Electronics Fundamentals
| Topic | Key Concepts | Application |
|---|---|---|
| Ohm's Law | V=IR, power P=VI | BEC current sizing (P=6V×10A=60W) |
| Pull-up resistors | R to VCC, open-drain signals | I2C bus: 4.7kΩ to 3.3V |
| Decoupling capacitors | 100nF ceramic per IC | Servo noise rejection |
| PWM signals | Frequency, duty cycle, pulse width | Servo control: 50Hz, 500–2400µs |
| I2C protocol | SDA/SCL, address, ACK/NACK | All sensors + PCA9685 |
| ADC conversion | 12-bit, reference voltage, sampling time | TCRT5000 line array |
| DMA transfers | Memory-to-peripheral without CPU | ADC1 circular DMA for IR array |

### 3. Git & Version Control
```bash
# Essential commands for this project:
git clone <repo>
git checkout -b feature/gait-engine    # Always branch for new features
git add firmware/Motion/gait_engine.c
git commit -m "feat: add trot gait diagonal phase"
git push origin feature/gait-engine
git pull origin main                   # Before starting new work
```

### 4. STM32CubeMX Setup
Learn to configure:
- **Clock**: HSE 25MHz → PLL → 100MHz SYSCLK
- **I2C1**: PB6(SCL), PB7(SDA), 400kHz, interrupt mode
- **I2C2**: PB10(SCL), PB3(SDA), 400kHz
- **ADC1**: IN0-8 (PA0-PA7, PB0), DMA1 Stream0 Ch0, circular
- **TIM2**: 20ms period (50Hz) → `update_flag` interrupt
- **TIM3**: 10ms period (100Hz) → IMU update interrupt
- **USART1**: PA9/PA10, 115200 baud, debug

## Practical Exercise
Write a bare-metal STM32 program that:
1. Blinks PC13 (built-in LED) at 1Hz using TIM2 interrupt
2. Sends `"Hello RUNNER-4\r\n"` via UART every 500ms
3. Reads a single ADC channel (PA0) and prints the value

## Prerequisite for Level 2
- Can write and compile a C program from scratch
- Understands pointers and structs
- Can generate a CubeMX project and add custom code in the `USER CODE` sections
- Can flash STM32 via ST-Link

---
🔙 **[Back to Curriculum](../README.md)**

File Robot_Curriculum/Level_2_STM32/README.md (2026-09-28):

# Level 2 — STM32 Firmware
## STM32F411CEU6 HAL, Peripherals, and PCA9685 Driver

## Why This Level Matters
RUNNER-4 has no operating system. Every sensor read, servo write, and timing decision is your firmware. Understanding HAL deeply prevents race conditions, I2C hangs, and ADC glitches under competition pressure.

## Topics

### 1. STM32F411CEU6 Architecture
```
Core:    ARM Cortex-M4F, 100MHz
Flash:   512 KB (code + calibration data in last sector)
RAM:     128 KB (stack, DMA buffers, gait arrays)
FPU:     Single-precision hardware float (atan2f, sinf = 1 cycle)
AHB:     DMA1/DMA2 for ADC + UART + SPI
APB1:    I2C1, I2C2, TIM2, TIM3, TIM4
APB2:    ADC1, USART1, TIM1
```

### 2. HAL I2C — PCA9685, MPU6050, VL53L0X, TCS34725

```c
/* I2C1 initialization (PB6=SCL, PB7=SDA, 400kHz) */
/* Generated by CubeMX, add this in USER CODE */

/* Write one register: */
uint8_t buf[2] = {reg_addr, value};
HAL_I2C_Master_Transmit(&hi2c1, device_addr << 1, buf, 2, HAL_MAX_DELAY);

/* Read one register: */
HAL_I2C_Master_Transmit(&hi2c1, device_addr << 1, &reg_addr, 1, 100);
HAL_I2C_Master_Receive (&hi2c1, device_addr << 1, &value, 1, 100);

/* Common mistake: HAL uses 8-bit address (7-bit addr << 1)
   PCA9685 address: 0x40 -> pass 0x80 to HAL */
```

**Device addresses (8-bit HAL format):**

| Device | 7-bit addr | HAL 8-bit | Bus |
|---|---|---|-----|
| PCA9685 | 0x40 | 0x80 | I2C1 |
| MPU6050 | 0x68 | 0xD0 | I2C1 |
| TCS34725 | 0x29 | 0x52 | I2C1 |
| VL53L0X Front | 0x30 | 0x60 | I2C2 |
| VL53L0X Left | 0x31 | 0x62 | I2C2 |
| VL53L0X Right | 0x32 | 0x64 | I2C2 |

### 3. PCA9685 PWM Driver

```c
/* Key registers */
#define PCA9685_MODE1    0x00   /* 0x20 = auto-increment, 0x10 = sleep */
#define PCA9685_PRESCALE 0xFE   /* Set frequency */
#define LED0_ON_L        0x06   /* CH0 base, each channel = +4 bytes */

/* Prescaler for 50Hz: round(25MHz / (4096 * 50)) - 1 = 121 */

/* Set PWM for one channel: */
void PCA9685_SetPWM(uint8_t ch, uint16_t on, uint16_t off) {
    uint8_t reg = LED0_ON_L + ch * 4;
    uint8_t buf[5] = {reg,
        on & 0xFF, on >> 8,
        off & 0xFF, off >> 8};
    HAL_I2C_Master_Transmit(&hi2c1, 0x80, buf, 5, HAL_MAX_DELAY);
}

/* Servo angle to tick (50Hz, MG90S): */
/* tick = 102 + (angle/180.0) * 389 */
/* 0° = 102 (500µs)   90° = 307 (1500µs)   180° = 491 (2400µs) */
```

### 4. ADC1 + DMA1 — 9-Channel IR Line Array

```c
/* CubeMX: ADC1, IN0-IN8 (PA0-PA7, PB0), DMA1 Stream0 Ch0, circular */
/* Each channel oversampled 16× in software for noise rejection */

#define LA_NUM_SENSORS  9
#define LA_OVERSAMPLE   16
#define LA_BUF_SIZE     (9 * 16)   /* 144 words */

volatile uint32_t adc_dma_buf[LA_BUF_SIZE];

void LA_Init(void) {
    HAL_ADC_Start_DMA(&hadc1, (uint32_t*)adc_dma_buf, LA_BUF_SIZE);
}

/* In 50Hz update loop — raw = average of 16 samples per sensor */
uint32_t raw = 0;
for (int k = 0; k < 16; k++)
    raw += adc_dma_buf[sensor_i * 16 + k];
raw /= 16;
```

### 5. Timer Interrupts (TIM2 + TIM3)

```c
/* TIM2: 20ms period -> 50Hz main loop trigger */
/* TIM3: 10ms period -> 100Hz IMU update */

volatile uint8_t update_flag = 0;

void HAL_TIM_PeriodElapsedCallback(TIM_HandleTypeDef *htim) {
    if (htim->Instance == TIM2) {
        update_flag = 1;    /* Signals main loop to run */
    }
    if (htim->Instance == TIM3) {
        MPU6050_Update(&himu);   /* 100Hz IMU complementary filter */
    }
}

/* In main() while loop: */
void App_Run(void) {
    if (!update_flag) return;   /* Exit if not yet 20ms */
    update_flag = 0;
    /* ... sensor reads, state machine, gait, IK, servo write ... */
}
```

### 6. UART Debug Interface

```c
/* USART1: PA9=TX, PA10=RX, 115200 baud */
/* Send debug string: */
char buf[128];
snprintf(buf, sizeof(buf), "[SM:%d] Vx=%.0f C=%.1f F=%d\r\n",
    state, sm_Vx, centroid, tof_front_mm);
HAL_UART_Transmit(&huart1, (uint8_t*)buf, strlen(buf), 50);

/* Receive command (for calibration): */
/* Implement via HAL_UART_Receive_IT and a command parser */
```

## Practical Exercises

1. **PCA9685 sweep test**: Make CH0 sweep 0° → 180° → 0° in a loop. Verify with oscilloscope: pulse width 500µs at 0°, 1500µs at 90°, 2400µs at 180°.
2. **I2C scan**: Write a program that tries all 127 addresses and prints the ones that ACK. Should find: 0x40, 0x68, 0x29 on I2C1; 0x30, 0x31, 0x32 on I2C2 (after VL53L0X remap).
3. **ADC DMA test**: Start ADC1 DMA, print all 9 sensor raw values via UART every 500ms. Cover sensors with hand → values change.
4. **50Hz timer test**: Toggle PC13 LED in TIM2 callback. Count toggles/second with a phone stopwatch → should be exactly 50.

## Prerequisite for Level 3
- Can configure PCA9685 and sweep all 15 servo channels via UART commands
- Can read and print all 9 ADC line sensor values
- Can read MPU6050 raw accel + gyro over I2C1
- Can read all 3 VL53L0X distances over I2C2
- TIM2 50Hz interrupt triggers main loop correctly

---
🔙 **[Back to Curriculum](../README.md)**

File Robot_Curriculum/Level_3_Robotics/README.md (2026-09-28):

# Level 3 — Robotics Core
## Inverse Kinematics, Trot Gait, PD Control, HFSM

## Why This Level Matters
The maths here is the difference between a robot that walks and one that falls over. Every competition run depends on the IK solver being correct and the gait engine being stable.

## Topics

### 1. Coordinate Frames

```
Body frame (fixed to robot chassis):
  X = forward (direction of travel)
  Y = left
  Z = up

Foot position expressed in body frame:
  FL neutral = (+80, +60, -50) mm
  FR neutral = (+80, -60, -50) mm
  BL neutral = (-80, +60, -50) mm
  BR neutral = (-80, -60, -50) mm

Body half-length = 80mm  (centre to front/rear coxa pivot)
Body half-width  = 60mm  (centre to left/right coxa pivot)
Stance depth     = 50mm  (foot below body, z = -50)
```

### 2. Inverse Kinematics — 3-DOF Geometric Solver

```
Link lengths: L1 (Coxa) = 30mm | L2 (Femur) = 60mm | L3 (Tibia) = 80mm
Max reach: L2 + L3 = 140mm | Min reach: |L2 - L3| = 20mm

Given target foot (fx, fy, fz):

Step 1 — Coxa yaw (horizontal plane):
  theta1 = atan2(fy, fx)

Step 2 — Elevation plane projection:
  d_xy    = sqrt(fx² + fy²) - L1      [horizontal reach past coxa]
  d_total = sqrt(d_xy² + fz²)         [femur-to-foot distance]
  Check:  20mm ≤ d_total ≤ 140mm     [reachability]

Step 3 — Femur angle (law of cosines):
  cos_beta = (L2² + d_total² - L3²) / (2·L2·d_total)
  alpha    = atan2(-fz, d_xy)         [elevation angle to foot]
  theta2   = alpha + acos(cos_beta)   [femur from horizontal]

Step 4 — Tibia angle (law of cosines):
  cos_gamma = (L2² + L3² - d_total²) / (2·L2·L3)
  theta3    = π - acos(cos_gamma)     [tibia fold angle]

Step 5 — Convert to servo degrees:
  coxa_servo  = theta1 * (180/π) + 90   [centred at 90°]
  femur_servo = theta2 * (180/π) + 90
  tibia_servo = theta3 * (180/π)
  For right-side (FR, BR): femur = 180 - femur, tibia = 180 - tibia
```

### 3. Trot Gait Engine

```
Gait parameters:
  Period T   = 600ms   (full cycle)
  Swing duty = 50%     (300ms in air)
  Stance duty= 50%     (300ms on ground)
  Step height= 35mm    (parabolic Z arc in swing)
  Phase offsets: FL=0.0, FR=0.5, BL=0.5, BR=0.0

Diagonal pairs: FL + BR swing together → FR + BL stance
               FR + BL swing together → FL + BR stance
Always 2 legs grounded → stable support

Foot trajectory:
  SWING:  x(t) = lerp(x_liftoff, x_land, t)
          y(t) = lerp(y_liftoff, y_land, t)
          z(t) = -body_h + step_height × sin(π·t)  [parabolic arc]

  STANCE: x(t) = x_land - Vx × stance_time × t   [body pushes over foot]
          z(t) = -body_h                            [foot on ground]

Landing target (feedforward):
  x_land = x_neutral + Vx × half_swing - Wz × y_neutral × half_swing
  y_land = y_neutral + Vy × half_swing + Wz × x_neutral × half_swing
```

### 4. PD Controllers

#### Line Following PD
```c
/* Input:  line centroid error [-4..+4] from 9-sensor array   */
/* Output: Wz (yaw rate rad/s) fed into GaitEngine_Update()   */

#define LINE_KP  0.012f   /* Proportional: rad/s per unit error */
#define LINE_KD  0.003f   /* Derivative: damping */
#define WZ_MAX   0.80f

float LinePD_Update(float err, float *prev, float dt) {
    float Wz = LINE_KP * err + LINE_KD * (err - *prev) / dt;
    *prev = err;
    return fmaxf(-WZ_MAX, fminf(WZ_MAX, Wz));
}

/* Tuning procedure:
   1. Set Kd=0, increase Kp until slow oscillation -> Kp_osc
   2. Set Kp = 0.5 * Kp_osc (typically 0.008-0.015)
   3. Increase Kd until oscillation damps (typically 0.001-0.005)
   Target: 1m straight + 90° corner without line loss */
```

#### Wall Following PD
```c
/* Input:  tof[LEFT].dist_mm, tof[RIGHT].dist_mm              */
/* Output: Wz to keep robot centred in corridor               */

#define WALL_KP  0.008f
#define WALL_KD  0.002f
#define WALL_WZ_MAX 0.60f

float WallPD_Update(float L, float R, float *prev, float dt) {
    float err = L - R;   /* +ve = drift right, turn left */
    float Wz = WALL_KP * err + WALL_KD * (err - *prev) / dt;
    *prev = err;
    return fmaxf(-WALL_WZ_MAX, fminf(WALL_WZ_MAX, Wz));
}
```

### 5. Hierarchical Finite State Machine (HFSM)

```
21 states, transitions triggered by sensor data each 20ms:

IDLE -> T1_LINE_FOLLOW -> T1_BALL_APPROACH -> T1_COLOR_ID
     -> T1_BALL_GRAB   -> T1_STORE         -> T1_GRID_EXIT
     -> T2_WALL_FOLLOW -> T3_WALL_FOLLOW   -> T3_OBSTACLE_DETECT
     -> T3_PUSH        -> T3_TURN          -> T4_LINE_FOLLOW
     -> T4_JUNCTION    -> T4_BRANCH        -> T4_BALL_RELEASE
     -> FINISH

Each state outputs:
  sm_Vx, sm_Vy:  body velocity mm/s  (into GaitEngine_Update)
  sm_Wz:         yaw rate rad/s
  sm_arm_pos:    ARM_HOME / ARM_MODE_A / ARM_MODE_B
  sm_gripper:    GRIPPER_OPEN / GRIPPER_CLOSE
  sm_gate:       GATE_LOCKED / GATE_OPEN
```

### 6. Complementary Filter (IMU)

```c
/* Fuses gyroscope (accurate short-term) with accelerometer (no drift)   */
/* CF_ALPHA = 0.98 -> trust gyro 98%, correct with accel 2% each cycle  */

pitch_deg = 0.98f * (pitch_deg + gy_dps * dt) + 0.02f * accel_pitch;
roll_deg  = 0.98f * (roll_deg  + gx_dps * dt) + 0.02f * accel_roll;

/* Used in Task 3: if |pitch_deg| > 20°, robot is tipping -> SAFE_STOP */
```

## Practical Exercises

1. **IK verification**: Command foot target FL=(80, 60, -50). Calculate theta1/2/3 by hand. Verify with `kinematics.c` output. Should give Coxa≈90°, Femur≈45°, Tibia≈135°.
2. **Static stance**: Call `IK_GetNeutralStance()` + `IK_SolveAll()` + `PCA9685_WriteLegs()`. Robot should stand level on all 4 feet.
3. **Slow trot**: Set Vx=20mm/s, Wz=0. Verify FL+BR lift together, then FR+BL. No toe drag (GAIT_STEP_HEIGHT ≥ 25mm).
4. **Line PD loop**: Wire 9 sensors, run line array + PD controller. Robot should follow a black tape line for 1m without loss.
5. **State machine stub**: Implement states 0-3 (BOOT → CALIB → IDLE → T1_LINE_FOLLOW). Press PC13 to trigger transition.

## Prerequisite for Level 4
- Static stance: robot stands level, all 4 feet grounded
- Slow trot stable at Vx=20mm/s for 30 seconds
- Line following at Vx=40mm/s tracks 2m of black tape
- State machine transitions 0→1→2→3 on button press

---
🔙 **[Back to Curriculum](../README.md)**

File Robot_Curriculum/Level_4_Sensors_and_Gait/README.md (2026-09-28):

# Level 4 — Sensors & Full Integration
## ToF + IR Array + TCS34725 + IMU + Full Mission Run

## Why This Level Matters
This is where individual subsystems merge into a robot that can autonomously complete all 4 competition tasks. By this level, each sensor driver and the gait engine are working individually — now integrate them and handle all the edge cases.

## Topics

### 1. VL53L0X ToF Sensor System

```
3 sensors on I2C2 (SDA=PB3, SCL=PB10):
  FRONT @ 0x30 — detects pedestals (Task 1), obstacles (Task 3)
  LEFT  @ 0x31 — wall following (Task 2)
  RIGHT @ 0x32 — wall following (Task 2)

Address remapping sequence (all boot at 0x29):
  1. PB12=PB13=PB14=LOW (all in reset)
  2. HAL_Delay(10)
  3. PB12 HIGH -> FRONT boots at 0x29 -> write 0x8A=0x30 -> FRONT=0x30
  4. PB13 HIGH -> LEFT  boots at 0x29 -> write 0x8A=0x31 -> LEFT =0x31
  5. PB14 HIGH -> RIGHT boots at 0x29 -> write 0x8A=0x32 -> RIGHT=0x32

Key thresholds:
  TOF_WALL_TARGET_MM   = 150  (corridor setpoint)
  TOF_GAP_THRESHOLD_MM = 250  (reading > this = gap/opening)
  TOF_OBSTACLE_MM      = 150  (Task 3: obstacle detected)
  TOF_BALL_APPROACH_MM =  80  (Task 1: stop at pedestal)
  TOF_GAP_CONSEC_MIN   =   3  (3 consecutive reads to confirm)

EMA filter: dist_ema = 0.4 * raw + 0.6 * prev  (alpha=0.4)
```

### 2. IR Line Array — 9-Channel TCRT5000

```
Sensor positions:  S1..S9, left to right, 10mm pitch, 80mm total
ADC DMA buffer:    9 sensors × 16 oversamples = 144 words (circular)

Processing pipeline:
  Layer 1: raw[i] = sum(dma_buf[i×16 .. i×16+15]) / 16
  Layer 2: ema[i] = 0.7 × raw[i] + 0.3 × ema_prev[i]
  Layer 3: spike reject if |ema[i] - prev| > 500 counts
  Normalise: lv[i] = 1.0 - clamp((ema[i]-cal_white[i]) / span, 0, 1)

  centroid = sum(i × lv[i]) / sum(lv[i])     [0..8 sensor index]
  error    = centroid - 4.0                   [-4..+4]
  error_mm = error × 10.0                    [-40..+40 mm]

Junction detection: active_count ≥ 6 for ≥ 3 consecutive cycles
Line lost:          sum(lv[i]) ≈ 0 for ≥ 5 cycles -> is_lost=true

Calibration via UART (run before every competition):
  "la_cal white\r\n" -> over white surface
  "la_cal black\r\n" -> over black tape -> saves to Flash
```

### 3. TCS34725 Colour Sensor

```
I2C1 @ 0x29 | Integration time: 50ms | Gain: 4x | LED: PC0=HIGH

Mounted on arm tip (CH12):
  ARM_MODE_A (0°):   sensor at ball height -> ball colour ID (Task 1)
  ARM_MODE_B (160°): sensor at floor level -> zone colour ID (Task 4)

Classification (ratio-dominance, normalised to clear channel):
  r_n = raw_r / raw_c    g_n = raw_g / raw_c    b_n = raw_b / raw_c

  RED:   r_n > 0.40 AND r_n > g_n×1.4 AND r_n > b_n×1.4
  GREEN: g_n > 0.35 AND g_n > r_n×1.2 AND g_n > b_n×1.2
  BLUE:  b_n > 0.30 AND b_n > r_n×1.2 AND b_n > g_n×1.2
  Else:  UNKNOWN

Stability filter: require 3 consecutive same-colour reads before acting
Non-blocking: sensor polled every 3rd 20ms cycle (60ms = faster than 50ms integration)

CRITICAL: Recalibrate thresholds under actual competition lighting.
Arena LED temperature matters — same ball reads differently under warm vs. cool LEDs.
Calibration procedure:
  ARM_MODE_A, LED ON, red ball -> read r_n, g_n, b_n
  Adjust TCS_RED_R_MIN to 0.85 × observed r_n
  Repeat for green and blue balls
```

### 4. MPU6050 IMU — Stability Monitor

```
I2C1 @ 0x68 | Range: ±500 dps gyro, ±2g accel | Update rate: 100Hz (TIM3 ISR)

Complementary filter (CF_ALPHA = 0.98):
  pitch_deg = 0.98 × (pitch_deg + gy_dps × 0.01) + 0.02 × accel_pitch
  roll_deg  = 0.98 × (roll_deg  + gx_dps × 0.01) + 0.02 × accel_roll

Used for:
  - Task 3 obstacle push: if |pitch_deg| > 20° -> robot tipping -> SAFE_STOP
  - Post-push verification: IMU level confirms robot recovered
  - Competition run: monitor for arena floor irregularities

IMU not used for locomotion control (gait is open-loop).
IMU is a safety guard only.
```

### 5. Full 50Hz Integration Loop

```
Every 20ms (TIM2 interrupt):

  1. LA_Update()              -> la.centroid, la.error, la.is_junction, la.is_lost
  2. TCS34725_Poll()          -> color (COLOR_RED/GREEN/BLUE/UNKNOWN)
  3. TOF_UpdateAll()          -> tof[0..2].dist_mm, tof[x].is_gap
  4. (TIM3 ISR, 100Hz)        -> pitch_deg, roll_deg (MPU6050)

  5. StateMachine_Update(s)   -> sm_Vx, sm_Vy, sm_Wz, sm_arm, sm_grip, sm_gate
     Internal PD controllers:
       sm_Wz = LinePD_Update(la.error)  in line-following states
       sm_Wz = WallPD_Update(L,R)       in wall-following states

  6. ARM_Update(arm,grip,gate) -> smooth slew CH12/13/14 via PCA9685
  7. GaitEngine_Update(Vx,Vy,Wz, feet)
  8. IK_SolveAll(feet, joints)
  9. PCA9685_WriteLegs(joints)

  Total: ~7.6ms / 20ms budget  (62% margin)
```

### 6. Competition Mission Sequence

```
Task 1 — Ball Retrieval (30-60s):
  Line follow at Vx=60 -> junction detected AND front<80mm
  -> ARM_MODE_A (800ms) -> colour ID (3 stable reads)
  -> GRIPPER_CLOSE (1200ms) -> ARM_HOME + GATE_LOCKED
  -> Line follow exit grid

Task 2 — Corridor (20-40s):
  Wall-follow at Vx=80 (L+R ToF PD)
  Gap detection: ToF>250mm × 3 readings = corridor opening

Task 3 — Obstacle Push (20-30s):
  Obstacle: FRONT<150mm × 3 readings -> slow push Vx=50
  Exit: FRONT>300mm OR 8s timeout -> in-place turn 3200ms @ Wz=-0.5 rad/s

Task 4 — Ball Release (30-50s):
  Line follow at Vx=60 -> junction
  -> ARM_MODE_B floor scan -> colour match × 3
  -> GATE_OPEN (1500ms) -> ball exits into correct zone
  -> FINISH
```

## Practical Exercises

1. **Sensor integration test**: Run full 50Hz loop with all sensors. Print one-line status via UART every 100ms:
   `[SM:3] C=4.1 F=200 L=155 R=145 col=0 p=0.3`

2. **Task 1 dry run**: Place a red ball 80mm from front sensor, run T1 sequence. Arm should reach, colour read RED, gripper close. Time it.

3. **Task 2 corridor run**: Set up two walls 300mm apart. Run wall-follow state. Robot should stay centred ±20mm for 1m.

4. **Task 3 obstacle**: Place a block 150mm from front. Robot should detect, push, then turn 90°.

5. **Full mission run**: Complete all 4 tasks sequentially under 3 minutes.

## Competition Preparation Tips

| Activity | When | Why |
|---|---|-----|
| la_cal white+black | Arrival at venue | Arena floor reflectance varies |
| Colour recalibrate | After arena lights on | LED temperature affects TCS34725 |
| Servo trim check | Before each run | Vibration shifts servo offsets |
| ToF scan verify | Before each run | Connector vibration can disconnect |
| Walk test 1m | 5min before run | Confirms gait stable in arena |

---
🔙 **[Back to Curriculum](../README.md)**

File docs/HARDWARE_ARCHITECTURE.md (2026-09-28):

# HARDWARE ARCHITECTURE

## 1. Overview
The hardware architecture of the RUNNER-4 quadruped robot is designed around a **single-controller embedded paradigm**. All perception, decision-making, and real-time control are handled by a single STM32F411CEU6 microcontroller. This eliminates the Raspberry Pi layer, reducing weight, power draw, and system complexity.

## 2. Compute Layer
- **Sole Controller**: STM32F411CEU6 (Black Pill). Responsible for bare-metal C programming, Mission State Machine, Inverse Kinematics, gait generation, sensor fusion, and safety watchdogs. Runs at 100MHz with hardware FPU.

## 3. Sensor Layer

| Sensor | Interface | Address/Pins | Purpose |
|---|---|---|---|
| **9-Channel TCRT5000 IR Line Array** | ADC1 + DMA1 | PA0–PA7, PB0 (9 pins) | Line following, weighted centroid, junction detection (≥6/9 active) |
| **TCS34725 RGBC Colour Sensor** | I2C1 | 0x29 | Ball colour ID (arm MODE_A 0°) + Floor zone colour ID (arm MODE_B 160°) |
| **MPU6050 IMU** | I2C1 | 0x68 | 6-axis gyro/accel, complementary filter, 100Hz tilt safety monitor |
| **VL53L0X ToF (Front)** | I2C2 | 0x30 (remap) | Ball pedestal approach (<80mm) + obstacle detect (<150mm) |
| **VL53L0X ToF (Left)** | I2C2 | 0x31 (remap) | Left wall distance for corridor wall-follow PD |
| **VL53L0X ToF (Right)** | I2C2 | 0x32 (remap) | Right wall distance for corridor wall-follow PD |

### Line Array Details
- Type: 9× TCRT5000 reflective IR, **analogue output → ADC1 + DMA1** (circular, 16× oversampling)
- Array width: 80mm total; sensor pitch: 10mm centre-to-centre
- Mount position: Front-underside of body, 5mm above floor, centred on robot midline
- Interface: S1–S8 on PA0–PA7 (ADC1 IN0-IN7), S9 on PB0 (ADC1 IN8)
- Pull-up: 10kΩ to 3.3V per sensor
- DMA buffer: 9 × 16 = 144 uint32 words (circular)
- Centroid formula: `error = centroid - 4.0` (range −4 to +4, 0 = centred)

### Colour Sensor Details
- Type: TCS34725 RGBC, I2C, 0x29 on I2C1
- Mount position: Gripper arm tip
- **MODE_A** (CH12 at 0°, arm horizontal forward): Reads ball colour at 1–2cm range at pedestal height
- **MODE_B** (CH12 at 160°, arm angled down to floor): Reads floor colour zone at 1–3cm range at junction
- Built-in white LED illuminator controlled via STM32 **PC0** (HIGH = LED ON during reads)
- Non-blocking polling: read available every ~120ms (3×20ms start + 3×20ms wait)

## 4. Actuation Layer
- **Servo Driver**: PCA9685 16-channel 12-bit PWM controller on I2C1 (0x40).
- **Leg Servos**: 12× MG90S (metal gear). CH0–CH11 on PCA9685. Coxa, Femur, Tibia for all four legs.
- **Arm Servo**: 1× MG90S. CH12. Controls gripper arm pitch (0° ball mode / −70° floor mode / home).
- **Gripper Servo**: 1× MG90S. CH13. Opens/closes claw around 40mm ball.
- **Storage Gate Servo**: 1× MG90S. CH14. Locks ball in internal compartment; releases by gravity.

## 5. Mechanical Integration
- **Chassis**: Custom 3D-printed PETG body. 3-tier deck: battery (bottom), STM32+PCA9685 (mid), sensor bar (top/front).
- **Leg Design**: 3-DOF per leg. **L1 (Coxa)=30mm**, **L2 (Femur)=60mm**, **L3 (Tibia)=80mm**. Max reach 140mm.
- **Gait**: Trot (diagonal FL+BR / FR+BL). Period 600ms, step height 35mm, Vx_max 100mm/s.
- **Line Array Bracket**: 9-sensor TCRT5000 bar, 80mm wide, 5mm above floor, held on front-underside bracket.
- **Arm Tip Mount**: Small 3D-printed shroud holds TCS34725 at gripper arm tip (CH12 pitch servo).

## 6. Block Diagram

```mermaid
flowchart TD
    subgraph Compute["Compute (Single Controller)"]
        STM["STM32F411CEU6 Black Pill\n100MHz · 512KB Flash · 128KB RAM"]
    end

    subgraph Sensors
        LINE["9× TCRT5000\nLine Array (ADC DMA)"]
        CLR["TCS34725\nColour Sensor"]
        IMU["MPU6050\nIMU 100Hz"]
        TOF["3× VL53L0X\nToF Sensors"]
    end

    subgraph Actuators
        PCA["PCA9685\nPWM Driver"]
        LEG["12× MG90S\nLeg Servos"]
        MECH["3× MG90S\nArm · Gripper · Gate"]
    end

    LINE -->|"ADC1 DMA PA0-PA7 PB0"| STM
    CLR  <-->|"I2C1 0x29"| STM
    IMU  <-->|"I2C1 0x68"| STM
    TOF  <-->|"I2C2 XSHUT PB12-14"| STM

    STM  <-->|"I2C1 0x40"| PCA
    PCA  ===|"PWM CH0–CH11"| LEG
    PCA  ===|"PWM CH12–CH14"| MECH
```

## 7. I2C Bus Summary

| Bus | Pins | Speed | Devices |
|-----|---|---|---|
| **I2C1** | PB6 (SCL) / PB7 (SDA) | 400kHz | PCA9685 (0x40), MPU6050 (0x68), TCS34725 (0x29) |
| **I2C2** | PB10 (SCL) / PB3 (SDA) | 400kHz | VL53L0X Front (0x30), Left (0x31), Right (0x32) |

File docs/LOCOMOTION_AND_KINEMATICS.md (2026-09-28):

# LOCOMOTION, KINEMATICS & GAIT CONTROL
## RUNNER-4 | Trot Gait | 3-DOF IK | L1=30mm L2=60mm L3=80mm

## 1. Coordinate Systems

```
World Frame (W):  Fixed to arena floor.
Body Frame (B):   Centre of robot chassis.
                  +X = forward (direction of travel)
                  +Y = left
                  +Z = up

Leg coxa pivot offsets from body centre:
  FL: (+80, +60,   0)   FR: (+80, -60,   0)
  BL: (-80, +60,   0)   BR: (-80, -60,   0)

Neutral foot positions (body frame, mm):
  FL: (+80, +60, -50)   FR: (+80, -60, -50)
  BL: (-80, +60, -50)   BR: (-80, -60, -50)
```

## 2. Link Lengths (Confirmed Hardware)

| Segment | Symbol | Length | Function |
|---|---|---|---|
| Coxa | L1 | **30 mm** | Horizontal yaw pivot, hip to femur |
| Femur | L2 | **60 mm** | Upper leg, load-bearing vertical link |
| Tibia | L3 | **80 mm** | Lower leg, ground contact |
| Max reach | L2+L3 | **140 mm** | From coxa pivot |
| Min reach | \|L2-L3\| | **20 mm** | From coxa pivot |
| Body half-len | Bl | 80 mm | Centre to front/rear coxa |
| Body half-wid | Bw | 60 mm | Centre to left/right coxa |

## 3. Inverse Kinematics (IK) — Geometric 3-DOF

### Derivation

```
Given target foot position (fx, fy, fz) in body frame:

STEP 1 — Coxa yaw angle (horizontal):
  theta1 = atan2(fy, fx)

STEP 2 — Elevation plane projection:
  d_xy    = sqrt(fx² + fy²) - L1     [horizontal reach past coxa]
  d_total = sqrt(d_xy² + fz²)        [femur-pivot to foot distance]

  Reachability: 20mm ≤ d_total ≤ 140mm

STEP 3 — Femur angle (law of cosines):
  cos_beta = (L2² + d_total² - L3²) / (2·L2·d_total)
  alpha    = atan2(-fz, d_xy)         [elevation angle to foot]
  theta2   = alpha + acos(cos_beta)   [femur from horizontal]

STEP 4 — Tibia angle (law of cosines):
  cos_gamma = (L2² + L3² - d_total²) / (2·L2·L3)
  theta3    = π - acos(cos_gamma)     [tibia fold angle]

STEP 5 — Convert to servo degrees:
  coxa_servo  = theta1 × (180/π) + 90   [centred = 90°]
  femur_servo = theta2 × (180/π) + 90
  tibia_servo = theta3 × (180/π)
  Right-side legs (FR, BR): femur_servo = 180 - femur_servo
                             tibia_servo = 180 - tibia_servo
```

### Neutral Stance Output Angles

| Leg | Coxa | Femur | Tibia | CH |
|-----|---|---|---|----|
| FL | 90° | 45° | 135° | CH0/1/2 |
| FR | 90° | 135° | 45° | CH3/4/5 |
| BL | 90° | 45° | 135° | CH6/7/8 |
| BR | 90° | 135° | 45° | CH9/10/11 |

### Implementation
- C code: `firmware/Motion/kinematics.h` + `kinematics.c`
- Key defines: `IK_L1_MM 30.0f` | `IK_L2_MM 60.0f` | `IK_L3_MM 80.0f`
- Function: `IK_SolveAll(feet[4], joint_angles_deg[12])`

## 4. Gait — Diagonal Trot

> **Gait selection:** Trot used exclusively. Crawl gait was previously considered but trot provides adequate stability for MG90S with 35mm step height on smooth arena floors.

### Phase Diagram

```
  Period T = 600ms | Swing = 50% (300ms) | Stance = 50% (300ms)

  Time:  0ms        300ms        600ms
         |            |            |
  FL:    [##SWING###][ STANCE     ]   Phase offset 0.0
  BR:    [##SWING###][ STANCE     ]   Phase offset 0.0
  FR:    [ STANCE    ][##SWING###]    Phase offset 0.5
  BL:    [ STANCE    ][##SWING###]    Phase offset 0.5

  2 legs always grounded -> stable diagonal support
```

### Foot Trajectory

```
SWING phase (parabolic arc):
  x(t) = lerp(x_liftoff, x_land, t_norm)
  y(t) = lerp(y_liftoff, y_land, t_norm)
  z(t) = -body_h + 35mm × sin(π × t_norm)   [35mm step height]

STANCE phase (body pushes forward over fixed foot):
  x(t) = x_land - Vx × stance_time × t_norm
  y(t) = y_land - Vy × stance_time × t_norm
  z(t) = -body_h   [foot stays on floor]

Swing landing target (velocity feedforward):
  x_land = x_neutral + Vx × 0.15 - Wz × y_neutral × 0.15
  y_land = y_neutral + Vy × 0.15 + Wz × x_neutral × 0.15
```

### Gait Parameters

| Parameter | Value | Range | Effect |
|---|---|---|---|
| Period T | 600ms | 400–800ms | Slower = more stable |
| Step height | 35mm | 25–55mm | Higher = clears obstacles |
| Vx_max | 100mm/s | — | Forward speed clamp |
| Vy_max | 60mm/s | — | Lateral speed clamp |
| Wz_max | 0.80 rad/s | — | Yaw rate clamp |
| body_h | 50mm | 40–70mm | Body height above floor |

### Implementation
- C code: `firmware/Motion/gait_engine.h` + `gait_engine.c`

## 5. Locomotion Control Hierarchy

```
9× TCRT5000 IR Array (ADC1 DMA) or 3× VL53L0X ToF (I2C2)
   → Sensor error signal (line centroid or wall difference)
   → PD Controller → Wz (rad/s steering command)
         │
Mission State Machine (50Hz, TIM2 interrupt)
   → Sets Vx, Vy, Wz per state
         │
GaitEngine_Update(Vx, Vy, Wz, feet[4])
   → 4 foot (X, Y, Z) targets in body frame
         │
IK_SolveAll(feet[4], joints[12])
   → 12 joint angles [Coxa, Femur, Tibia × 4 legs]
         │
PCA9685_WriteLegs(joints[12]) via I2C1
   → 15× MG90S servo PWM → Physical motion
         │
MPU6050 IMU (100Hz, TIM3 ISR)
   → Complementary filter → pitch, roll
   → Safety watchdog only (open-loop gait — no postural correction)
```

## 6. PD Controllers

### Line Following PD
```c
#define LINE_KP   0.012f
#define LINE_KD   0.003f
#define WZ_MAX    0.80f     /* rad/s */

/* error = centroid - 4.0, range [-4..+4] */
float LinePD_Update(float err, float *prev, float dt_s) {
    float Wz = LINE_KP * err + LINE_KD * (err - *prev) / dt_s;
    *prev = err;
    return fmaxf(-WZ_MAX, fminf(WZ_MAX, Wz));
}
```

### Wall Following PD
```c
#define WALL_KP      0.008f
#define WALL_KD      0.002f
#define WALL_WZ_MAX  0.60f   /* rad/s */

/* error = left_mm - right_mm (+ve = drift right = turn left) */
float WallPD_Update(float L, float R, float *prev, float dt_s) {
    float err = L - R;
    float Wz = WALL_KP * err + WALL_KD * (err - *prev) / dt_s;
    *prev = err;
    return fmaxf(-WALL_WZ_MAX, fminf(WALL_WZ_MAX, Wz));
}
```

---
🔙 **[Back to docs](./README.md)**

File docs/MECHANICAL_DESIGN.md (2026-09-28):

# MECHANICAL DESIGN

## 1. Overview
The RUNNER-4 quadruped mechanical chassis is optimised for a low centre of gravity (CoG), symmetrical mass distribution, and specific task execution (grasping, sensing, and pushing) decoupled from the primary locomotion gait.

## 2. Base Chassis

- **Material**: 3D-printed PETG (heat-resistant, impact-tough). 25–30% infill for structural parts.
- **Form Factor**: Symmetrical rectangle, target body ~160×140mm (≤250×250mm footprint with legs folded).
- **Multi-Deck Component Placement**:
  - **Bottom Deck**: 2S LiPo battery (heaviest component) mounted perfectly centred (lowest CoG).
  - **Middle Deck**: STM32F411 + PCA9685 + 5V/15A BEC + power distribution.
  - **Top Deck**: Debug header connector, LED indicators, power switch access.
  - **Front-Underside**: 8-channel TCRT5000 IR line array bracket (see Section 5).
  - **Front Face**: 3× VL53L0X ToF sensors (front, left-front, right-front corners).
  - **Front Arm**: 2-DOF arm+gripper with TCS34725 at tip (see Section 4).
  - **Front-Bottom**: Passive PETG bumper plate.

> [!NOTE]
> The Raspberry Pi 4B, Pi Camera Module, CSI ribbon cable, and separate 5V/3A Pi power regulator have been removed from this design. The top deck is now free and lighter.

## 3. Leg Design
- **Configuration**: 12-DOF (3-DOF per leg × 4 legs).
- **Joints**:
  1. **Coxa (Shoulder Yaw ±45°)**: Sweeps the leg forward/backward and laterally.
  2. **Femur (Shoulder Pitch ±60°)**: Lifts the leg.
  3. **Tibia (Knee Pitch 0°–135°)**: Extends the leg downward.
- **Link Lengths**: **L1 (Coxa)=30mm, L2 (Femur)=60mm, L3 (Tibia)=80mm** (confirmed hardware dimensions).
- **Max reach from coxa pivot**: 60+80 = **140mm** | Min reach: |60-80| = **20mm**
- **Symmetry**: All servos mechanically zeroed (90°) before attaching horns (see calibration guide).
- **Foot**: Small rounded tip with rubber O-ring for traction on matte arena surface.

## 4. SubTask 01: Ball Arm + Gripper (with TCS34725)
- **Design**: 2-DOF frontal arm (arm pitch + claw open/close).
- **Mechanism**:
  - **Arm Pitch Servo (CH12)**: Rotates the arm to three calibrated positions:
    - `HOME` (90°): Resting/travel position — arm vertical, safe for walking.
    - `MODE_A` (0° horizontal): Ball colour reading and grasp position — arm forward at pedestal height.
    - `MODE_B` (160° downward): Floor zone colour reading — arm angles to floor below front of robot.
  - **Gripper Servo (CH13)**: Opens (60°) and closes (115°) claw around 40mm ball.
  - **Gate Servo (CH14)**: Locks ball in internal compartment (0°); opens for gravity release (90°).
- **TCS34725 Colour Sensor Mounting**:
  - Sensor mounted rigidly at the arm tip.
  - A small 3D-printed shroud around the sensor blocks ambient arena light, ensuring the built-in LED is the primary light source for consistent readings.
  - When arm is in MODE A, sensor is ~1–2cm from ball surface — within TCS34725 optimal range.
  - When arm is in MODE B, sensor is ~1–3cm from floor line — within TCS34725 optimal range.
- **Why arm-tip mounting**: The arm's range of motion allows the single sensor to serve both the ball-reading task (elevated pedestal) and the floor-reading task (ground level), eliminating the need for a second sensor.

## 5. Line Array Bracket
- **Sensor**: 9-channel TCRT5000 IR array (analogue, ADC1 DMA).
- **Mount Position**: Front-underside of main body chassis, centred on robot midline, perpendicular to forward axis.
- **Mount Height**: 5mm above floor surface (TCRT5000 optimal at 5mm).
- **Array Width**: 80mm total, 10mm pitch, S1-S9 left to right (PA0-PA7, PB0).
- **Wiring**: S1-S8 signal wires to STM32 ADC1 PA0-PA7; S9 to PB0. 10kΩ pull-up to 3.3V per channel.
- **DMA Buffer**: ADC1 + DMA1 circular, 9×16 = 144 words. 16× oversampling per sensor.

## 6. SubTask 03: Obstacle Pushing Bumper
- **Design**: A flat, ~80–100mm wide, 50mm tall rigid bumper plate attached to the lower front chassis.
- **Material**: PETG, 50%+ infill for rigidity.
- **Why**: The Task 03 obstacle is 25×25×20cm. The flat bumper maximises contact area and transfers leg push force into the obstacle without leg entanglement.
- **No moving parts**: Pure passive structure — zero failure modes.

## 7. Centre of Mass Analysis
- Battery (bottom-centre) ensures lowest possible CoG.
- 3-DOF legs with L1=30 L2=60 L3=80mm: foot reaches up to 140mm from coxa pivot.
- At neutral stance (all feet at z=-50mm), body is 50mm above floor.
- TCS34725 at arm tip (~5g) has negligible CoM impact.
- When ball (~30g) is stored in front belly compartment: CoM shifts forward ~+2mm — within trot support polygon.
- During trot (2-leg stance FL+BR or FR+BL), support triangle is ~160mm × 120mm — CoG stays inside at Vx up to ~100mm/s.

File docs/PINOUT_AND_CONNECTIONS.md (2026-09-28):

# PINOUT AND CONNECTIONS

## 1. Authoritative Hardware Mapping

> [!WARNING]
> Do not deviate from these mappings without updating this document. If a conflict arises between code and this document, the hardware must be re-verified.

---

### STM32F411CEU6 (Black Pill) — Complete Pin Assignment

| STM32 Pin | Function | Connected To | Voltage | Notes |
|---|---|---|---|---|
| **PA0** | ADC1_IN0 — Line S1 | TCRT5000 S1 OUT | 3.3V | Leftmost IR sensor (analogue) |
| **PA1** | ADC1_IN1 — Line S2 | TCRT5000 S2 OUT | 3.3V | |
| **PA2** | ADC1_IN2 — Line S3 | TCRT5000 S3 OUT | 3.3V | |
| **PA3** | ADC1_IN3 — Line S4 | TCRT5000 S4 OUT | 3.3V | Left-centre |
| **PA4** | ADC1_IN4 — Line S5 | TCRT5000 S5 OUT | 3.3V | Centre sensor |
| **PA5** | ADC1_IN5 — Line S6 | TCRT5000 S6 OUT | 3.3V | Right-centre |
| **PA6** | ADC1_IN6 — Line S7 | TCRT5000 S7 OUT | 3.3V | |
| **PA7** | ADC1_IN7 — Line S8 | TCRT5000 S8 OUT | 3.3V | |
| **PB0** | ADC1_IN8 — Line S9 | TCRT5000 S9 OUT | 3.3V | Rightmost IR sensor |
| **PA9** | USART1 TX | Debug PC (RX) | 3.3V | **Dev only — disconnect at competition** |
| **PA10** | USART1 RX | Debug PC (TX) | 3.3V | **Dev only — disconnect at competition** |
| **PB3** | I2C2 SDA | 3× VL53L0X SDA | 3.3V | ToF sensor bus |
| **PB6** | I2C1 SCL | PCA9685, MPU6050, TCS34725 SCL | 3.3V | Main I2C bus |
| **PB7** | I2C1 SDA | PCA9685, MPU6050, TCS34725 SDA | 3.3V | Main I2C bus |
| **PB10** | I2C2 SCL | 3× VL53L0X SCL | 3.3V | ToF sensor bus |
| **PB12** | GPIO OUT — XSHUT1 | VL53L0X Front XSHUT | 3.3V | Address remap control |
| **PB13** | GPIO OUT — XSHUT2 | VL53L0X Left XSHUT | 3.3V | Address remap control |
| **PB14** | GPIO OUT — XSHUT3 | VL53L0X Right XSHUT | 3.3V | Address remap control |
| **PC0** | GPIO OUT — LED | TCS34725 LED pin | 3.3V | Controls built-in illuminator |
| **PC1** | ADC1 IN11 | Battery voltage divider | 3.3V | Low-battery detection |
| **PC13** | Start Button | Tactile switch to GND | 3.3V | Active LOW (built-in pull-up) |
| **GND** | Ground | All sensor and peripheral GND | 0V | Star ground topology |
| **3V3** | Power Out | STM32 → Sensors (LDO) | 3.3V | MPU, ToF, TCS34725, Line Array |

> [!IMPORTANT]
> IR sensors use **ADC1 + DMA1** (analogue), NOT digital GPIO. CubeMX: ADC1 IN0-IN7 on PA0-PA7, IN8 on PB0. DMA1 Stream0 CH0 circular, 144 word buffer (9 sensors × 16 oversamples).

### 9-Channel TCRT5000 Line Array Connections

| Line Array Pin | Connected To | Mode | Notes |
|---|---|---|---|
| **VCC** | STM32 3.3V | — | |
| **GND** | Common GND | — | |
| **S1 OUT** | STM32 PA0 | ADC1_IN0 | 10kΩ pull-up to 3.3V |
| **S2 OUT** | STM32 PA1 | ADC1_IN1 | |
| **S3 OUT** | STM32 PA2 | ADC1_IN2 | |
| **S4 OUT** | STM32 PA3 | ADC1_IN3 | |
| **S5 OUT** | STM32 PA4 | ADC1_IN4 | Centre sensor (error=0 when S5 active) |
| **S6 OUT** | STM32 PA5 | ADC1_IN5 | |
| **S7 OUT** | STM32 PA6 | ADC1_IN6 | |
| **S8 OUT** | STM32 PA7 | ADC1_IN7 | |
| **S9 OUT** | STM32 PB0 | ADC1_IN8 | Rightmost sensor |

---

### TCS34725 Colour Sensor Connections

| TCS34725 Pin | Connected To | Voltage | Notes |
|---|---|---|---|
| **VCC** | STM32 3.3V | 3.3V | |
| **GND** | Common GND | 0V | |
| **SCL** | STM32 PB6 | 3.3V | I2C1 bus |
| **SDA** | STM32 PB7 | 3.3V | I2C1 bus |
| **LED** | STM32 PC0 | 3.3V | GPIO output; HIGH = LED ON during reads |
| **INT** | Not connected | — | Interrupt pin (unused — polling mode) |

---

### PCA9685 Servo Controller

| PCA Pin | Function | Connected To | Notes |
|---|---|---|---|
| **VCC** | Logic Power | STM32 3.3V | I2C pull-ups |
| **SDA** | Data | STM32 PB7 | I2C1 |
| **SCL** | Clock | STM32 PB6 | I2C1 |
| **GND** | Logic Ground | Common GND | |
| **V+ (Terminal)** | Motor Power | 5V–6V / 15A BEC | High-current servo rail |
| **GND (Terminal)** | Motor Ground | Common GND | |
| **PWM 0–2** | Leg FL | Front Left (Coxa, Femur, Tibia) | |
| **PWM 3–5** | Leg FR | Front Right (Coxa, Femur, Tibia) | |
| **PWM 6–8** | Leg BL | Back Left (Coxa, Femur, Tibia) | |
| **PWM 9–11** | Leg BR | Back Right (Coxa, Femur, Tibia) | |
| **PWM 12** | Arm Pitch | Ball arm elevation servo | HOME=90° | MODE_A=0° | MODE_B=160° |
| **PWM 13** | Gripper | Claw open/close | |
| **PWM 14** | Storage Gate | Ball compartment gate | |
| **PWM 15** | *Spare* | Available | |

---

### VL53L0X Time-of-Flight Sensors (×3)

All three share I2C2 (PB10/PB3). Each has a dedicated XSHUT pin for boot-time address reassignment.

| Sensor | XSHUT Pin | Final I2C Address | Mounting Position |
|---|---|---|---|
| **Front** | PB12 | `0x30` | Front-centre, 25mm above ground, 0° (forward) |
| **Left** | PB13 | `0x31` | Front-left corner, 25mm above ground, 90° (left) |
| **Right** | PB14 | `0x32` | Front-right corner, 25mm above ground, 90° (right) |

---

## 2. Complete I2C Address Map

| Device | Bus | Default Addr | Runtime Addr | Changeable? |
|---|-----|---|---|---|
| **PCA9685** | I2C1 | `0x40` | `0x40` | Yes (solder A0–A5) |
| **MPU6050** | I2C1 | `0x68` | `0x68` | Yes (AD0 pin) |
| **TCS34725** | I2C1 | `0x29` | `0x29` | No |
| **VL53L0X Front** | I2C2 | `0x29` | `0x30` | Via XSHUT remap at boot |
| **VL53L0X Left** | I2C2 | `0x29` | `0x31` | Via XSHUT remap at boot |
| **VL53L0X Right** | I2C2 | `0x29` | `0x32` | Via XSHUT remap at boot |

> [!NOTE]
> TCS34725 (0x29 on I2C1) and VL53L0X (0x29 default on I2C2) share the same address by coincidence but are on **different I2C buses** — no conflict exists.

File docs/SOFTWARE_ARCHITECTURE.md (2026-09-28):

# SOFTWARE ARCHITECTURE

## 1. Single-Domain Design
The entire software system resides on a **single STM32F411CEU6** running bare-metal C (HAL). There is no Raspberry Pi, no Linux OS, no Python, and no inter-CPU communication. All perception, mission logic, and motor control operate within one deterministic 50Hz control loop.

## 2. Firmware (STM32F411) — Complete System

### Directory Structure
```text
firmware/
├── Core/
│   ├── Src/main.c               # Entry point; init all peripherals; main while(1) loop
│   ├── Src/stm32f4xx_it.c       # Interrupt handlers (TIM2 50Hz, I2C, EXTI)
│   └── Src/system_stm32f4xx.c   # Clock config (100MHz via PLL)
├── Drivers/
│   ├── PCA9685/
│   │   ├── pca9685.h
│   │   └── pca9685.c            # I2C PWM driver: init, set channel, angle→tick
│   ├── VL53L0X/
│   │   ├── vl53l0x.h
│   │   └── vl53l0x.c            # ToF driver: XSHUT remap, range read, median filter
│   ├── MPU6050/
│   │   ├── mpu6050.h
│   │   └── mpu6050.c            # IMU driver: raw read, complementary filter
│   ├── TCS34725/                 ← Colour sensor driver
│   │   ├── tcs34725.h
│   │   └── tcs34725.c           # I2C RGBC read, integration time, colour classify
│   └── LineArray/                ← 9-channel ADC+DMA IR line sensor driver
│       ├── line_array.h
│       └── line_array.c         # ADC1 DMA circular, EMA filter, centroid, junction
├── Motion/                       ← Replaces old Control/ folder
│   ├── kinematics.h / kinematics.c    # 3-DOF geometric IK (L1=30 L2=60 L3=80mm)
│   ├── gait_engine.h / gait_engine.c  # Trot gait: diagonal FL+BR/FR+BL, T=600ms
│   └── arm_controller.h / arm_controller.c  # CH12 arm + CH13 grip + CH14 gate slew
└── Navigation/                   ← NEW: Replaces entire Raspberry Pi Python layer
    ├── state_machine.h / state_machine.c  # Mission HFSM (18 states, all 4 subtasks)
    ├── line_follower.h / line_follower.c  # PD controller from 8-sensor centroid
    └── task_planner.h / task_planner.c    # Arm sequencing, ball grab, push, release
```

### 50Hz Process Flow (STM32 — Full System)
`TIM2` interrupt fires every 20ms, setting `update_flag = 1`. The main `while(1)` loop executes:

```c
if (update_flag) {
    update_flag = 0;

    /* ─── PERCEPTION ────────────────────────────────────────────────── */
    // 1. Read 9-channel line array (ADC1 DMA circular — always running)
    LA_Update(&la_result);      // EMA filter, centroid, junction detect
    float   line_error   = la_result.error;       // -4.0 to +4.0
    bool    intersection = la_result.is_junction; // >=6/9 sensors, >=3 cycles
    bool    line_lost    = la_result.is_lost;

    // 2. Read IMU (I2C1 — ~1ms)
    MPU6050_Read(&pitch, &roll);

    // 3. Read 3× VL53L0X ToF (I2C2 — ~3ms total)
    tof_front = VL53L0X_GetRange(TOF_FRONT);
    tof_left  = VL53L0X_GetRange(TOF_LEFT);
    tof_right = VL53L0X_GetRange(TOF_RIGHT);

    // 4. Read TCS34725 (I2C1 — non-blocking, 50ms integration
    //    result polled every 5 cycles = 10Hz effective)
    if (colour_cycle_counter++ >= 5) {
        colour_cycle_counter = 0;
        TCS34725_ReadRGBC(&r, &g, &b, &clear);
        last_color = TCS34725_ClassifyColor(r, g, b, clear);
    }

    /* ─── DECISION ───────────────────────────────────────────── */
    // 5. Run Mission State Machine (uses all sensor data above)
    StateMachine_Update(line_bits, line_error, intersection,
                        tof_front, tof_left, tof_right,
                        last_color, pitch, roll);

    /* ─── CONTROL ────────────────────────────────────────────── */
    // 6. Apply IMU postural corrections to foot targets
    PID_ApplyPostureCorrection(pitch, roll, foot_targets);

    // 7. Update trot gait phase → compute next foot positions
    GaitEngine_Update(sm_Vx, sm_Vy, sm_Wz, foot_targets);

    // 8. Solve Inverse Kinematics → 12 joint angles
    Kinematics_SolveAll(foot_targets, joint_angles);

    // 9. Write PWM to PCA9685 via I2C1 (~2ms)
    PCA9685_WriteAllChannels(joint_angles);

    /* ─── SAFETY ────────────────────────────────────────────────    */
    // 10. Safety: IMU tilt > 20° -> SAFE_STOP
    if (fabsf(pitch_deg) > 20.0f || fabsf(roll_deg) > 20.0f)
        StateMachine_Transition(STATE_SAFE_STOP);
}
```

### State Machine Overview
The Mission HFSM (`Navigation/state_machine.c`) contains **18 states** covering all four competition subtasks:

```
BOOT_INIT → SENSOR_CALIB → IDLE_WAIT_START
  → TASK1_LINE_FOLLOW → TASK1_BALL_APPROACH → TASK1_COLOR_ID
  → TASK1_BALL_GRAB → TASK1_STORE → TASK1_GRID_EXIT
  → TASK2_WALL_FOLLOW
  → TASK3_WALL_FOLLOW → TASK3_OBSTACLE_DETECT → TASK3_PUSH → TASK3_TURN
  → TASK4_LINE_FOLLOW → TASK4_JUNCTION_DETECT → TASK4_BRANCH_FOLLOW
  → TASK4_BALL_RELEASE → FINISH
  → SAFE_STOP (any state on fault) → ERROR_RECOVERY
```

Key persistent variable: `stored_ball_color` — written to STM32 Flash via EEPROM emulation after Task 1 colour identification. Survives STM32 reset (competition restarts).

## 3. End-to-End Data Flow

```
8× TCRT5000 Line Array (GPIO)
    → Weighted centroid error
    → PD line follower → Wz (angular velocity)
    → State Machine → gait Vx, Vy, Wz targets
    → Gait Generator → 4 foot target (x,y,z) positions
    → IK Solver → 12 joint angles (θ1,θ2,θ3 per leg)
    → PCA9685 (I2C) → 15× MG90S servo PWM
    → Physical movement

TCS34725 Colour Sensor (I2C1, arm tip)
    → R/G/B/Clear raw values → colour ratio classification
    → STATE_MACHINE: stored_ball_color (Task 1) / branch selection (Task 4)

3× VL53L0X ToF (I2C2)
    → Wall PD centering (Task 2/3) / obstacle detect (Task 3)

MPU6050 IMU (I2C1)
    → Complementary filter → pitch, roll
    → Postural PID → foot Z offsets for level walking
```

## 4. Debug Interface (Development Only)
- **USART1** (PA9 TX, PA10 RX, 115200 baud): Outputs state machine transitions, sensor values, and timing data via serial terminal during development.
- **MUST be disconnected before competition** (no external communication allowed by rules).
- Use ST-Link SWD for firmware flashing and GDB debugging.

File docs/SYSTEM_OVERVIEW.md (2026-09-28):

# SYSTEM OVERVIEW

## 1. High-Level Concept
The FusionForce RUNNER-4 quadruped is designed around a fundamental principle in embedded robotics: **Simplicity through Integration**.

Instead of splitting workload across two processors (a Raspberry Pi for vision + an STM32 for control), the architecture consolidates all perception, decision-making, and motor control onto a **single STM32F411CEU6 microcontroller**. This eliminates inter-CPU communication overhead, Linux boot delays, UART failure points, and weight penalties — all critical advantages in a time-limited, weight-constrained competition.

## 2. The Two Engineering Domains

The system is divided into two domains. This division dictates hardware placement, software architecture, and team responsibilities.

### Domain 1: STM32 + Embedded Sensing (The "Brain + Spine")
This single layer handles all cognitive functions AND all real-time control. It knows where to go and exactly how to move the legs to get there.
- **Hardware**: STM32F411CEU6 (Black Pill), 9-Channel TCRT5000 IR Line Array (ADC DMA), TCS34725 RGBC Colour Sensor, MPU6050 IMU, 3× VL53L0X ToF Sensors.
- **Software**: Bare-metal C using STM32 HAL. 50Hz deterministic control loop.
- **Responsibilities**:
  - Reading 9-channel IR line array via ADC1+DMA (analogue, 16× oversampled) for line following and junction detection.
  - Reading TCS34725 colour sensor for ball colour identification (Task 01, arm MODE_A 0°) and floor zone detection (Task 04, arm MODE_B 160°).
  - Running the Mission Hierarchical Finite State Machine (HFSM) — all 4 subtasks.
  - Inverse Kinematics (IK) math: L1=30mm, L2=60mm, L3=80mm geometric solver.
  - Generating **trot gait** (diagonal FL+BR / FR+BL pairs, T=600ms, step height=35mm).
  - Sending PWM target angles to the PCA9685 via I2C1 at 50Hz.
  - Reading MPU6050 IMU at 100Hz (TIM3 ISR) as safety tilt watchdog only.
  - Reading ToF sensors for wall-distance feedback and obstacle detection.
  - Persisting `stored_ball_color` in Flash across power cycles/restarts.

### Domain 2: Mechanical & Locomotion (The "Body")
This layer translates the mathematical outputs of Domain 1 into physical motion.
- **Hardware**: 3D-printed PETG chassis, 12× MG90S leg servos, 1× MG90S arm pitch, 1× MG90S gripper, 1× MG90S storage gate, passive front bumper.
- **Responsibilities**:
  - Providing a stable physical platform (Centre of Gravity optimisation).
  - Executing the physical crawl gait without slipping or stalling.
  - Physically grasping the ball and pushing the block.

## 3. High-Level Architecture Diagram

```text
         ┌──────────────────────────────────────────────────────┐
         │             DOMAIN 1: BRAIN + SPINE                  │
         │                                                      │
         │  ┌─ PERCEPTION ──────────────────────────────────┐   │
         │  │  9× TCRT5000 IR Array (ADC1+DMA PA0-PA7,PB0) │   │
         │  │   → Line centroid ±4.0, Junction detect (≥6/9) │   │
         │  │ TCS34725 Colour Sensor (I2C1, 0x29, arm tip)   │   │
         │  │   → Ball colour (MODE_A 0°) + Floor zone (MODE_B 160°)│
         │  │ MPU6050 IMU (I2C1, 0x68)                       │   │
         │  │   → Pitch/roll at 100Hz, tilt safety watchdog   │   │
         │  │ 3× VL53L0X ToF (I2C2, XSHUT-addressed)        │   │
         │  │   → Wall distances (PD ctrl) + obstacle detect   │   │
         │  └───────────────────────────────────────────────────┘   │
         │                       │                              │
         │  ┌─ CONTROL ──────────▼──────────────────────────┐   │
         │  │ STM32F411CEU6 (100MHz, 512KB Flash, 128KB RAM) │   │
         │  │  Mission State Machine (21 states, all tasks)  │   │
         │  │  Trot Gait Engine (L1=30 L2=60 L3=80mm, 600ms) │  │
         │  │  Inverse Kinematics (3-DOF per leg, 4 legs)    │   │
         │  │  PD Line + Wall Controllers → Wz commands       │   │
         │  └────────────────────┬──────────────────────────┘   │
         └───────────────────────┼──────────────────────────────┘
                                 │
                         I2C1 (400kHz)
                                 │
         ┌───────────────────────▼──────────────────────────────┐
         │                 DOMAIN 2: BODY                       │
         │                                                      │
         │  PCA9685 (I2C1, 0x40) — 16-ch PWM servo driver      │
         │  12× MG90S Leg Servos  (CH0–CH11)                    │
         │  1×  MG90S Arm Pitch   (CH12)                        │
         │  1×  MG90S Gripper     (CH13)                        │
         │  1×  MG90S Storage Gate (CH14)                       │
         │  Passive Front Bumper — Task 03 obstacle pushing     │
         └──────────────────────────────────────────────────────┘
```

## 4. Why This Architecture?

* **Real-Time Determinism**: The STM32 bare-metal C loop runs exactly every 20ms (50Hz), with no OS preemption. Every sensor read and every servo update is predictable and bounded.
* **Instant Boot**: The STM32 initialises in <500ms. No 30-second Linux boot, no SD card dependency, no filesystem corruption risk.
* **No Inter-CPU Failure Point**: The original Pi→STM32 UART link was a single point of failure. A single corrupted packet or Pi crash could halt the robot. With one CPU, this failure mode is eliminated entirely.
* **Weight & Power**: Removing the Raspberry Pi 4B (46g, 1.5A) and its power regulator saves **~73g** and **~1.5A** average current draw — extending estimated runtime from 24 minutes to 35+ minutes.
* **Deterministic Colour Detection**: The TCS34725 is a dedicated RGBC sensor — its readings are unaffected by frame rate, motion blur, or image compression. It produces stable, low-latency colour values regardless of robot vibration.
* **Simplicity**: Fewer boards, fewer cables, fewer failure modes. One flash target, one debugging interface, one codebase in one language (C).

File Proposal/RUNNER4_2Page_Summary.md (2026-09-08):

# RUNNER-4 Autonomous Quadruped Robot — 2-Page Proposal Summary
### FusionForce Robotics | EN2533 Robotic Design and Competition | 5 September 2026

---

## Overall Strategy

RUNNER-4 is a 12-DOF autonomous quadruped robot designed to complete four sequential subtasks: grid navigation with ball pickup, curved wall-following with gap handling, obstacle pushing, and colour-based ball sorting. The design prioritises **reliability over speed**, using a slow crawl gait (one leg swinging at a time) that guarantees static stability with three feet always on the ground. A **single-MCU architecture** places all perception, mission decision-making, and real-time motor control on one STM32F411CEU6. An 8-channel TCRT5000 IR line array handles line following and intersection detection; a TCS34725 RGBC colour sensor (mounted on the gripper arm tip) handles ball colour identification and floor zone detection in dual-mode. Three VL53L0X ToF sensors handle wall-following and obstacle detection in corridors. The robot is powered by a **2S LiPo** to save weight, with a dedicated 5V/15A BEC providing high-current headroom for the actuators.

## Mechanical Design

The robot uses a **4-leg configuration with 3 joints per leg** (coxa/hip yaw, femur/hip pitch, tibia/knee pitch), totalling 12-DOF for locomotion. Proposed link lengths are L_coxa = 25 mm, L_femur = 50 mm, L_tibia = 55 mm. The body uses a **2-tier deck** construction (~160 × 140 mm): battery at bottom (lowest centre of mass), and STM32 + PCA9685 at the top level to save weight. A 2-servo **arm + gripper** at the front reaches the 5 cm ball pedestal, grasps the 40 mm ball, and deposits it into an **internal belly compartment** with a **servo-controlled gate** for secure storage and gravity-assisted release. A **passive front bumper plate** provides the pushing surface for Subtask 3, using the quadruped's leg force with no additional actuators. Target standing footprint: ≤ 250 × 250 mm. Estimated total mass: ~550 g. Material: 3D-printed PETG.

## Sensors

| Sensor | Qty | Function |
|---|-----|---|
| **8-ch TCRT5000 IR array** (GPIO PA0–PA7) | 1 | Line following, intersection/junction detection via weighted centroid |
| **TCS34725 RGBC** (I2C1, arm tip) | 1 | MODE A (arm 0°): ball colour; MODE B (arm −70°): floor zone colour |
| **VL53L0X ToF** | 3 | Wall distance (left/right), obstacle detection (front), corridor centering |
| **MPU6050 IMU** | 1 | Body pitch/roll for stabilization, tilt detection, push monitoring |
| **Start Button** | 1 | Single onboard switch for autonomous start |

The **line array** is mounted front-underside at 5–8mm floor height, centred on the robot midline. The **TCS34725** is at the gripper arm tip with a 3D-printed light shroud. ToF sensors are at the front-left, front-centre, and front-right corners. The IMU is centre-mounted at the body's centre of mass.

## Actuators

**15 × MG90S metal-gear micro servos** (2.2 kg·cm @ 6V, 13.4 g each):
- 12 for locomotion (3 per leg × 4 legs)
- 1 for ball arm pitch
- 1 for gripper open/close
- 1 for compartment gate

All driven by a **single PCA9685** 16-channel PWM servo driver (15/16 channels used). Servos operate at 6V from a dedicated **5V–6V / 15A switching BEC**, isolated from the logic power rail. Torque analysis confirms MG90S is sufficient for crawl gait (1.4× safety margin at estimated mass) but insufficient for trot gait — crawl gait is used exclusively.

## Algorithms

| Algorithm | Implementation | Processor |
|---|---|---|
| **3-DOF Inverse Kinematics** | Trigonometric solver (atan2, law of cosines) for 4 legs per 20 ms cycle | STM32 (C) |
| **Crawl Gait Generator** | Bezier-curve foot trajectories; FL→BR→FR→BL diagonal sequence; 2.0s cycle | STM32 (C) |
| **IMU Stabilization** | Complementary filter (α=0.98) + proportional pitch/roll correction to foot heights | STM32 (C) |
| **Line Following (PD)** | 8-sensor weighted centroid error → PD controller → Wz steering command | STM32 (C) |
| **Colour Classification** | TCS34725 R/G/B normalised ratios; non-blocking 50ms integration | STM32 (C) |
| **Wall Following** | Dual-ToF PD centering (error = d_left − d_right) with **gap rejection filter** | STM32 (C) |
| **Obstacle Pushing** | Front ToF detection → lower body → widen stance → slow crawl push → IMU tilt monitoring | STM32 (C) |
| **Mission State Machine** | 18-state HFSM (all 4 subtasks); Flash-persistent ball colour; 50Hz loop | STM32 (C) |

**Key algorithmic innovation**: The wall gap rejection filter distinguishes actual wall gaps from noise by requiring 3+ consecutive readings above threshold before switching to single-wall following mode, preventing the robot from steering into gaps.

**Perception approach**: No camera or Raspberry Pi is used to eliminate boot delays and save weight. We rely entirely on the 8-channel IR array for line following and the TCS34725 sensor for ball and floor color classification. The ball color is persisted in Flash EEPROM to survive restarts.

## Task Delegation

| Team | Responsibility | Deliverables |
|---|---|---|
| **Mechanical** | Body + leg CAD; 3D printing; arm with TCS34725 tip mount; line array bracket; bumper | SolidWorks assemblies; printed/assembled robot |
| **Electronics** | Power distribution; BEC selection (2S input); wiring harness; battery monitoring ADC | Tested power system; wiring diagrams |
| **STM32 Firmware** | IK solver; gait engine; IMU; all sensor drivers (TCRT5000+TCS34725+VL53L0X); state machine | C firmware; walking + full sensor test results |
| **Integration** | End-to-end testing; sensor calibration; competition prep; 2-min calibration routine | Test reports; competition checklist |

## System Architecture

```
8×TCRT5000 (PA0–PA7) ──────────────────────────────────────┐
TCS34725 (I2C1, arm tip) ──┐                               │
MPU6050  (I2C1)  ────────┤→ [STM32F411CEU6] → [PCA9685] → 15×MG90S
3×VL53L0X (I2C2) ────────┘   (Perception+FSM+IK+Gait+50Hz)

Power: 2S LiPo → 5V/15A BEC (Servos) + 3.3V LDO (Logic)
```

## Key Design Decisions

| Decision | Choice | Rationale |
|---|---|---|
| Gait | Crawl only | MG90S insufficient for trot; static stability guaranteed |
| Ball mechanism | 2-servo arm + gripper | Ball on 5cm pedestal requires active reach |
| Perception | TCRT5000 array + TCS34725 | Sub-ms line reads; dual-mode colour sensor replaces camera+Pi |
| Pushing | Passive bumper | Zero additional actuators; high reliability |
| **Battery** | **2S LiPo** | Reduced weight; Pi removed saves 1.5A; ~37 min runtime; no brownout risk |

**Estimated runtime**: ~37 min (2S LiPo) — easily covering the 15-min competition limit. **Top risk**: MG90S torque margin. **Mitigation**: Strict mass control and exclusive use of the crawl gait.

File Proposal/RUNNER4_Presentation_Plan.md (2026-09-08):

# RUNNER-4 — 10-Minute Presentation Plan

## Time Budget: 10:00 (strict — do NOT exceed)

---

## Slide Plan & Speaker Assignments

> Adjust speaker names as needed. Assumes 5 team members (A–E). All must present.

| Slide # | Section | Duration | Speaker | Content |
|---|---|---|---|---|
| 1 | **Title + Team** | 0:20 | A | Team name, competition name, date, team members |
| 2 | **Problem Statement** | 0:30 | A | 4 subtasks overview; 250mm footprint; 15-min time; fully autonomous |
| 3 | **Overall Strategy** | 0:40 | A | Crawl gait for stability; single STM32 handles all perception + decision; 8-ch IR array replaces camera for line following; TCS34725 on arm tip for colour detection; passive pushing |
| 4 | **System Architecture** | 0:30 | B | Block diagram: STM32F411 ↔ I2C1 (PCA9685+MPU6050+TCS34725) ↔ I2C2 (3×VL53L0X); GPIO PA0–PA7 (line array); power tree (BEC + 3.3V LDO) |
| 5 | **Actuators** | 0:40 | C | 15× MG90S; torque analysis (2.2 kg·cm vs 1.53 required); why crawl not trot; PCA9685 single board |
| 6 | **Sensors** | 0:50 | C | **8-ch TCRT5000 line array** (line/intersection/junction); **TCS34725 on arm tip** (ball colour + floor zone, dual mode); 3× VL53L0X ToF (wall/obstacle); MPU6050 (stabilization); sensor placement diagram |
| 7 | **Mechanical Design** | 1:00 | B | 12-DOF quadruped; leg geometry; link lengths; body dimensions; 3D printed PETG; footprint compliance |
| 8 | **Ball Mechanism** | 0:40 | B | 2-servo arm + gripper; internal compartment; servo gate; why scoop doesn't work (5cm pedestal) |
| 9 | **Pushing Mechanism** | 0:20 | B | Passive front bumper; low stance strategy |
| 10 | **Embedded Perception** | 0:50 | C | **Why no camera/Pi?** Boot delay, weight, failure point; TCRT5000 weighted centroid algorithm; TCS34725 R/G/B ratio classification; arm dual-mode (MODE A 0° ball / MODE B −70° floor); temporal filter for intersection detection |
| 11 | **STM32F411 + Control** | 0:30 | D | F411CEU6 (512KB Flash needed for state machine + all drivers); 50Hz control loop; IK solver; gait generator; IMU filter; Flash EEPROM for ball colour persistence |
| 12 | **Algorithms** | 1:00 | D | IK equations; crawl gait sequence; PD line following; PD wall following; gap rejection filter |
| 13 | **Subtask Walkthrough** | 1:00 | D | Step through all 4 subtasks: grid→ball→corridor→push→sort→finish; state machine flow |
| 14 | **Power System** | 0:20 | E | 2S LiPo; 5V/15A BEC (servos); 3.3V LDO (STM32+sensors); separate rails; **~37 min runtime** (Pi removed saves 1.5A) |
| 15 | **Task Delegation** | 0:30 | E | 5 team areas; who does what; development timeline |
| 16 | **Risks + Mitigation** | 0:30 | E | Top 5 risks: servo torque, TCS34725 ambient light, intersection false trigger, ball colour memory loss on restart (Flash persistence), loop timing overflow; backup plans |
| 17 | **Conclusion** | 0:20 | E | Design philosophy (reliability > speed); confidence in approach; ready for build |
| | **TOTAL** | **10:00** | | |

---

## Key Presentation Tips

1. **Practice the timing** — each speaker rehearses their section individually, then run full team rehearsal
2. **Transitions**: Each speaker ends with "Now [Name] will cover..." for smooth handoffs
3. **Visually rich slides**: Use the CAD screenshots, system architecture diagram, state machine diagram, and component photos
4. **Avoid reading slides** — speak to the evaluators, not the screen
5. **Anticipate Q&A** — see the Q&A preparation document

## Must-Show Visuals

- [ ] System architecture block diagram
- [ ] CAD render / photo of robot design
- [ ] Leg kinematic diagram with link lengths
- [ ] Ball mechanism concept sketch
- [ ] Sensor placement diagram (top view)
- [ ] Power tree schematic
- [ ] State machine flow diagram
- [ ] Torque feasibility table
- [ ] Pi comparison table

---

## Detailed Speaker Script & Talking Points

### Slide 1: Title + Team (Speaker A - 0:20)
- **Slide Content**: Project RUNNER-4, Team FusionForce, Event & Date.
- **Suggested Visual**: High-quality 3D CAD render of the RUNNER-4 robot on the title screen, with team and competition logos.
- **Speaker Script**: 
  - *"Good morning evaluators, and welcome. We are Team FusionForce, and today we are excited to present our final design for Project RUNNER-4. Before we begin, I'd like to quickly introduce the team: Minura and Thilishan lead our Mechanical Design, Pulina and Thushanthan handle Electronics and Power, Sandaru and Pulina are responsible for Control Systems and Software, while Minura and Thushanthan spearhead our Testing and Validation."*

### Slide 2: Problem Statement (Speaker A - 0:30)
- **Slide Content**: Fully autonomous navigation of 4 distinct subtasks, strict 250mm footprint limit, 15-minute maximum time limit.
- **Suggested Visual**: "Full Tasks Design Diagram" showing a zoomed-out, top-down view of the entire course (Grid $\rightarrow$ Corridors $\rightarrow$ Sorting Zone).
- **Speaker Script**: 
  - *"Our core challenge is to design a fully autonomous robot that can successfully navigate a circuit of four distinct subtasks. We must do all of this while adhering to a strict 250-millimeter footprint limit, and within a maximum time of 15 minutes. The four phases include: First, navigating a grid to retrieve a colored ball. Second, following a corridor while ignoring a gap in the wall. Third, pushing an obstacle out of our path in a second corridor. And finally, arriving at a junction to sort the ball into the correct zone based on the color we detected earlier."*

### Slide 3: Overall Strategy (Speaker A - 0:40)
- **Slide Content**: Crawl gait for maximum stability, centralized control via single STM32, 8-channel IR array for robust line following, arm-mounted sensor for direct color detection, passive pushing mechanism.
- **Suggested Visual**: Collage of key components (STM32 board, IR array, side-profile sketch of a quadruped walking).
- **Speaker Script**: 
  - *"Our overall strategy for RUNNER-4 prioritizes reliability and stability over raw speed. For locomotion, we've implemented a crawl gait to ensure three feet are always securely on the ground. Computationally, we've moved away from heavy processors like a Raspberry Pi, instead unifying perception, decision-making, and control onto a single STM32 microcontroller. To make this possible, we replaced complex camera vision with a fast 8-channel IR array for line following and a precision color sensor mounted directly on the gripper arm. Finally, to keep the design lightweight and simple, we're using a passive front bumper for the pushing task rather than adding extra motors."*

### Slide 4: System Architecture (Speaker B - 0:30)
- **Slide Content**: Central MCU: STM32F411, I2C1 Bus: Actuators, IMU, Color Sensor, I2C2 Bus: ToF Wall Sensors, Split Power Tree: 3.3V Logic / 5V Actuators.
- **Suggested Visual**: System Architecture Block Diagram showing the STM32 in the center, arrows pointing to I2C1, I2C2, and GPIO, and color-coded power delivery paths.
- **Speaker Script**: 
  - *"Taking a look at our system architecture diagram, everything centers around the STM32F411 microcontroller. We've carefully managed our data buses to prevent bottlenecks. The I2C1 bus handles our actuator driver, the IMU, and the color sensor, while we've dedicated the I2C2 bus entirely to our three Time-of-Flight wall sensors. Our 8-channel line array is read directly via fast GPIO pins. Crucially, as you can see at the bottom, our power tree is completely split: a 3.3-volt LDO provides clean power to the logic and sensors, while a heavy-duty 5-volt BEC provides dedicated, high-current power exclusively to the servos."*

### Slide 5: Actuators (Speaker C - 0:40)
- **Slide Content**: 15x MG90S Micro Servos, Torque Feasibility: 1.53 kg·cm required (2.2 kg·cm max), Driven by a single PCA9685 board.
- **Suggested Visual**: Photo of the MG90S servo and a simple bar chart comparing "Required Torque" vs "Max Torque".
- **Speaker Script**: 
  - *"For actuation, RUNNER-4 uses a total of 15 MG90S micro servos, all driven by a single PCA9685 board to simplify our wiring harness. During our design phase, we performed a strict torque analysis. We found that our joints require a maximum of 1.53 kilogram-centimeters of torque, which sits comfortably below the MG90S's 2.2 maximum rating. However, this safety margin is only valid for a crawl gait where only one leg lifts at a time. Attempting a trot gait would overstress these motors, which firmly validated our decision to use the slower, statically stable crawl gait."*

### Slide 6: Sensors (Speaker C - 0:50)
- **Slide Content**: 8-ch TCRT5000: Line & intersection tracking, TCS34725: Ball & floor zone color sensing, 3x VL53L0X ToF: Wall & gap detection, MPU6050 IMU: Body stabilization.
- **Suggested Visual**: Bottom-up or top-down drawing of the robot with bright markers pointing to where the IR array, ToF sensors, and Color sensor are mounted.
- **Speaker Script**: 
  - *"Here you can see our sensor placement diagram. Underneath the front chassis, we have an 8-channel TCRT5000 IR array which gives us high-resolution line and intersection tracking. On the tip of the arm is our TCS34725 color sensor; we cleverly use this one sensor for two purposes: reading the ball color when the arm is raised, and reading the floor sorting zones when the arm is angled down. For spatial awareness in the corridors, we mounted three Time-of-Flight sensors on the front left, right, and center. Lastly, an IMU sits directly at the center of mass to monitor body tilt during the pushing task."*

### Slide 7: Mechanical Design (Speaker B - 1:00)
- **Slide Content**: 12-DOF Quadruped chassis, 3D-printed PETG construction, optimized leg geometry, compliant with 250mm footprint.
- **Suggested Visual**: 2D kinematic diagram of a single leg (link lengths & joint angles) next to a top-down CAD view with a 250x250mm bounding box overlay.
- **Speaker Script**: 
  - *"For the mechanical design, we built a 12-DOF quadruped chassis from 3D-printed PETG. This material gives us the perfect balance of durability and weight savings, keeping our total mass under 550 grams. The leg geometry and specific link lengths were carefully optimized to provide sufficient ground clearance for obstacles while ensuring a stable stride. Crucially, as you can see in the footprint overlay, our design fits entirely within a 250 by 250-millimeter bounding box, maintaining strict compliance with the competition's size constraints."*

### Slide 8: Ball Mechanism (Speaker B - 0:40)
- **Slide Content**: 2-Servo arm & gripper assembly, internal compartment with secure servo gate, replaces scoop mechanisms.
- **Suggested Visual**: Zoomed-in CAD render of the 2-servo arm and gripper holding a ball, with a transparent view showing the internal storage compartment.
- **Speaker Script**: 
  - *"Handling the ball in Task 1 required a reliable mechanism. We rejected a simple scoop design because it wouldn't be able to retrieve a ball sitting on a 5-centimeter pedestal or handle uneven terrain. Instead, we designed an active 2-servo arm with a custom gripper. This arm reaches out, securely grasps the 40-millimeter ball, and pulls it into an internal belly compartment. Once inside, a third servo controls a gate that securely locks the ball in place for the remainder of the circuit until it's time for a gravity-assisted drop-off in Task 4."*

### Slide 9: Pushing Mechanism (Speaker B - 0:20)
- **Slide Content**: Passive front bumper design, utilizes "low stance" for maximum traction, eliminates active plow.
- **Suggested Visual**: Side-profile illustration of the robot in its "low stance" making contact with the block obstacle.
- **Speaker Script**: 
  - *"For the pushing task, we wanted to avoid the complexity and weight of an extra motor or active plow. Therefore, we integrated a passive flat bumper plate into the front chassis. When the ToF sensors detect the heavy obstacle in Task 3, the robot intentionally drops into a 'low stance'. This lowers our center of mass and maximizes leg traction, allowing the robot to use its own quadruped leg force to efficiently bulldoze the obstacle out of the way before standing back up."*

### Slide 10: Embedded Perception (Speaker C - 0:50)
- **Slide Content**: Weighted centroid algorithm for lines, R/G/B ratio classification for color, temporal filtering for gaps, no Raspberry Pi delays.
- **Suggested Visual**: Simple graphic showing a black line underneath an 8-sensor array, with a red dot showing the "calculated center" to explain the weighted centroid algorithm.
- **Speaker Script**: 
  - *"For perception, we made a crucial decision to omit a Raspberry Pi and camera setup. This eliminates boot delays, saves weight, and removes a major point of failure. Instead, we rely entirely on IR and color sensors. For line tracking, we use a weighted centroid algorithm on our 8-channel IR array to pinpoint the exact center of the line. For color, our TCS34725 sensor uses an R/G/B ratio classification and operates in two physical modes: zero degrees to look at the ball, and negative seventy degrees to look at the floor. Finally, to prevent false triggers at intersections, we implemented a robust temporal filter."*

### Slide 11: STM32F411 + Control (Speaker D - 0:30)
- **Slide Content**: 512KB Flash, responsive 50Hz control loop, Flash EEPROM for ball color persistence.
- **Suggested Visual**: Photo of the STM32F411 microcontroller and a simple loop graphic ("Read Sensors -> Process State -> Move Servos" at 50Hz).
- **Speaker Script**: 
  - *"At the heart of RUNNER-4 is the STM32F411 microcontroller. We specifically chose the CEU6 variant because its 512 kilobytes of flash memory provides ample space for our complex state machines and all sensor drivers. The entire system runs on a strict 50-Hertz control loop, ensuring the robot remains highly responsive. This loop handles everything, including integrating the inverse kinematics solver with our gait generator. An important safety feature we've added is using the Flash memory as an EEPROM to persist the detected ball color; if the robot ever loses power and restarts, it won't forget the ball's color for the final sorting task."*
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

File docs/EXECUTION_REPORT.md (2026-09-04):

# EXECUTION REPORT

## Project State Summary
**Current Phase**: Phase 0 (Planning & Documentation Setup)
**Overall Status**: NOT STARTED (Implementation phase pending)

## Starting State
The repository contained basic preliminary documentation (`Quadruped_Robot_Hardware_Plan.md` and some scattered files in `/docs`). The architecture was highly conceptual without clear boundaries or integration plans.

## Current Repository State
The repository has been restructured. The `Task/` directory contains authoritative task definitions. The `/docs` folder has been purged of outdated files (moved to `archive/`) and is currently being populated with authoritative engineering blueprints, plans, and checklists.
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

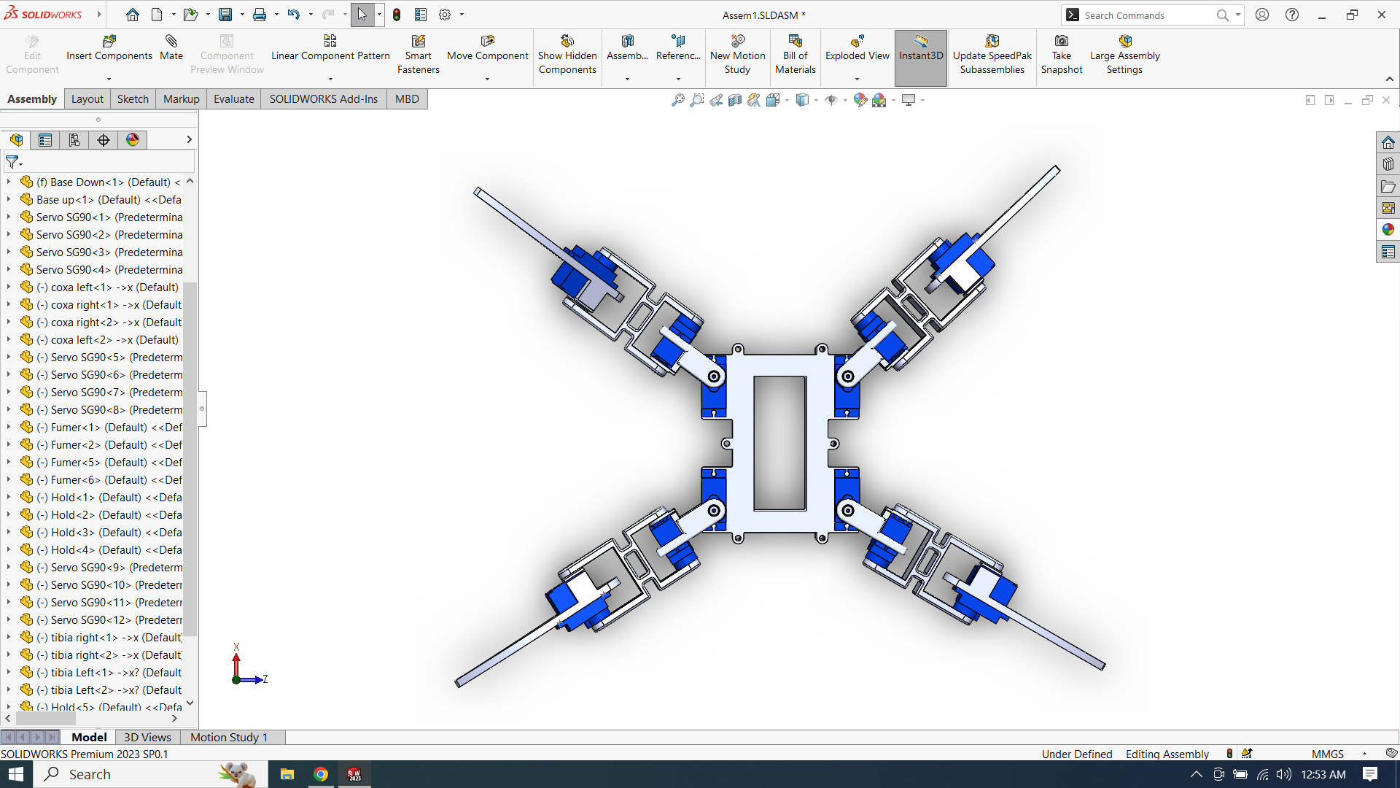
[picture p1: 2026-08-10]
3D designs/quadruped-spider-2.snapshot.2 (1)/Screenshot (3).png

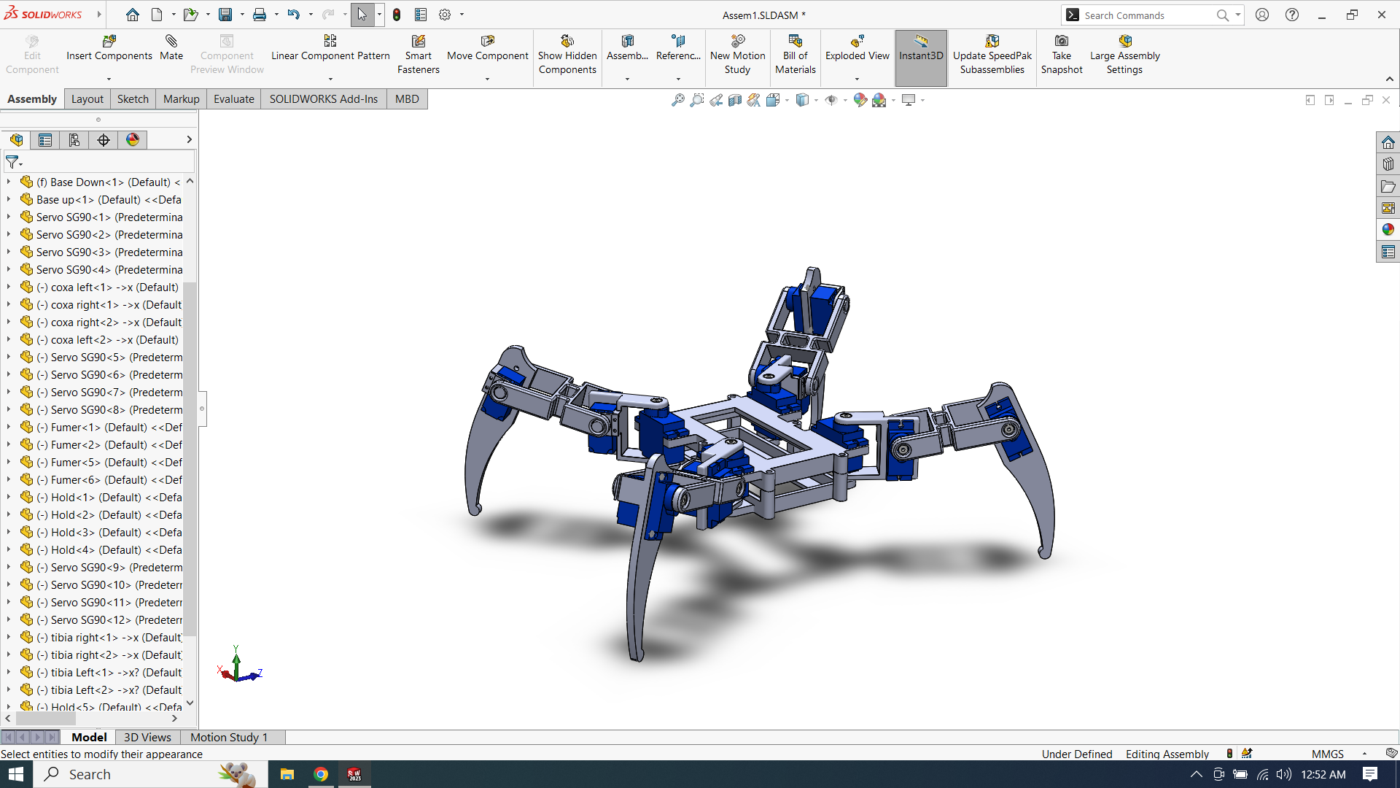
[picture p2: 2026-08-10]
3D designs/quadruped-spider-2.snapshot.2 (1)/Screenshot (2).png

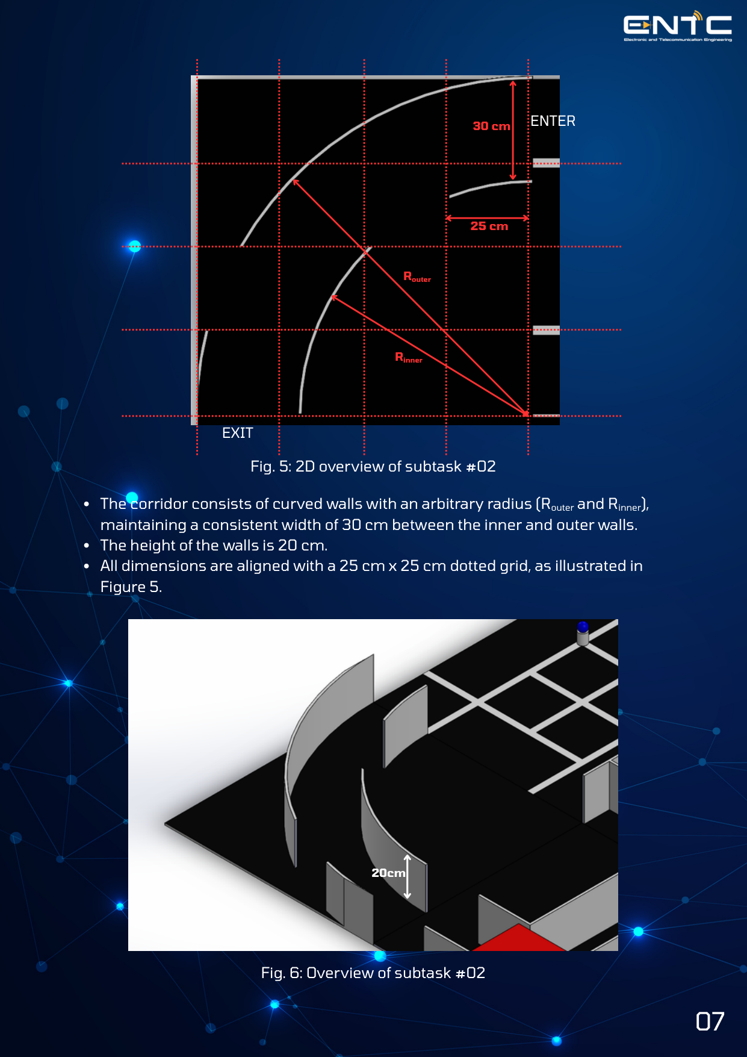
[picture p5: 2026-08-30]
Task/images/v2_page_7.png

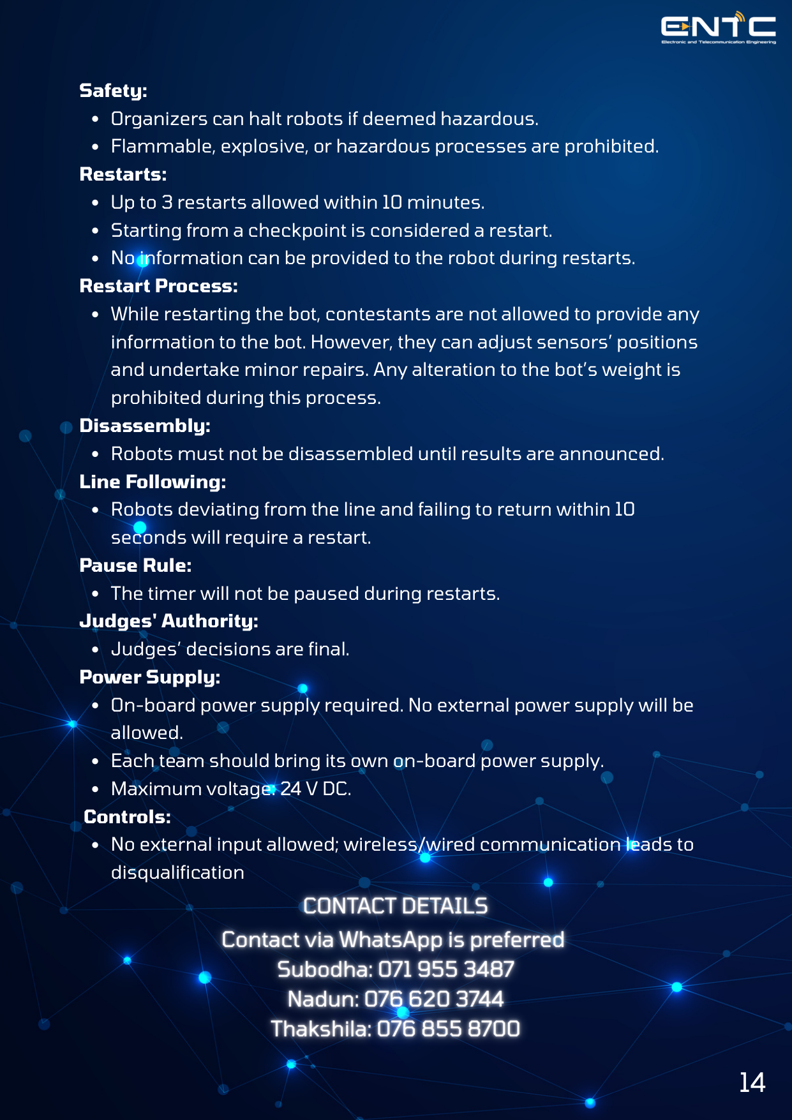
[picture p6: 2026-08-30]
Task/images/v2_page_14.png

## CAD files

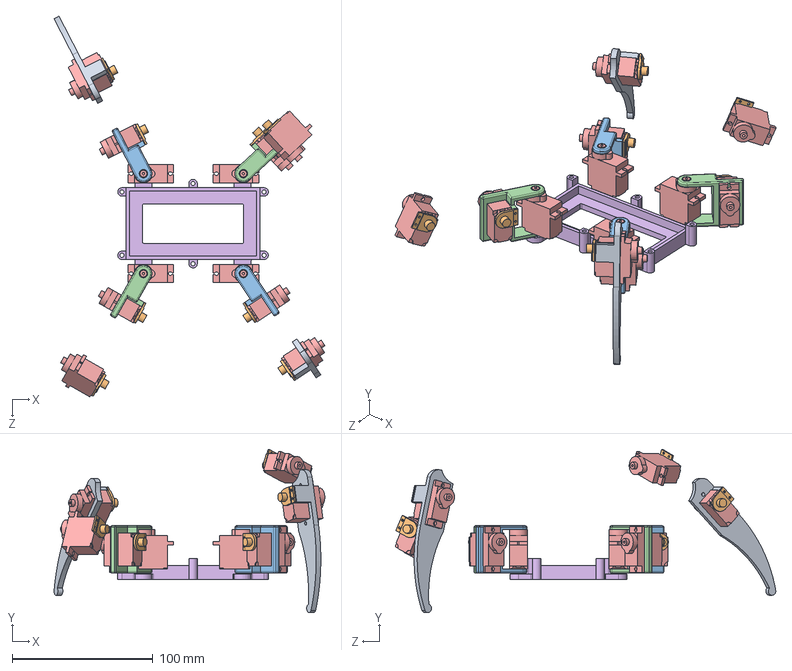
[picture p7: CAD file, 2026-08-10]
3D designs/quadruped-spider-2.snapshot.2 (1)/Assem1.SLDASM
192.5 x 116.0 x 270.5 mm
Base Down
Servo SG90 x 12
coxa left x 2
coxa right x 2
Hold x 8
tibia Left x 2

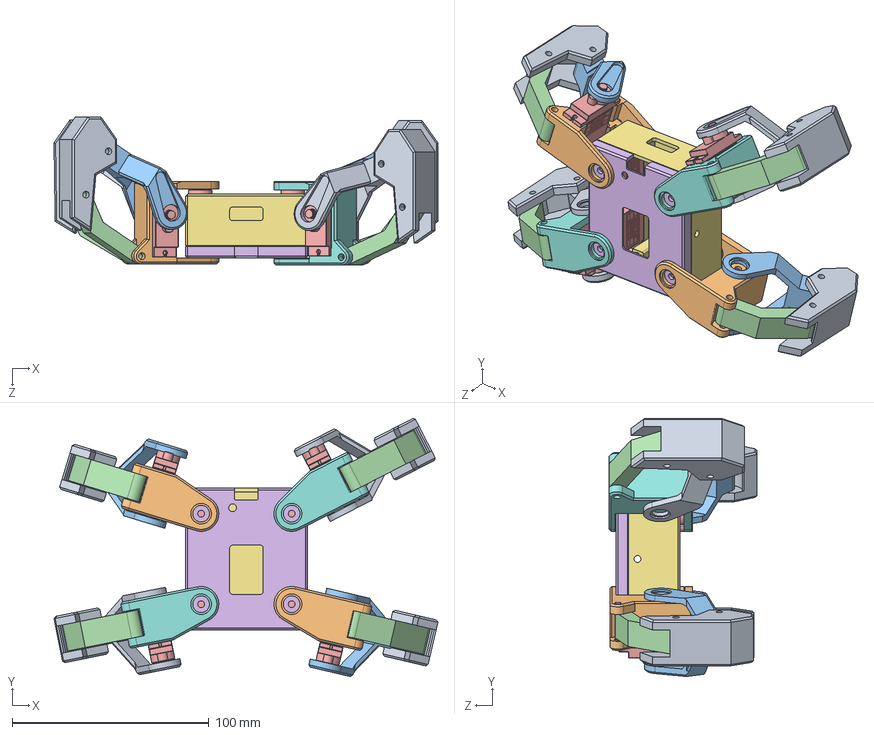
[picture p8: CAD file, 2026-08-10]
3D designs/quadruped-robot-7.snapshot.7 (1)/quadruped/Assem1.SLDASM
195.1 x 131.2 x 75.2 mm
foot x 4
leftBracket x 2
leftLegB x 2
legA x 4
MG90s_servo x 8
bodyA
bodyB
rightBracket x 2
rightLegB x 2

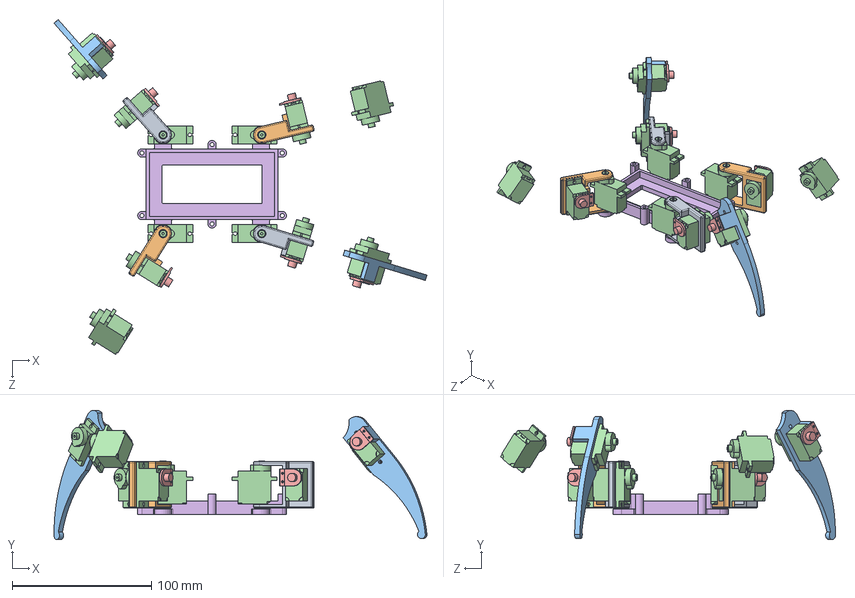
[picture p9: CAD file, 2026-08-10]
3D designs/quadruped-spider-2.snapshot.2 (1)/SPIDER.SLDASM
268.3 x 92.8 x 240.9 mm
Base Down
Hold x 6
Servo SG90 x 12
tibia Left x 2
coxa left x 2
coxa right x 2

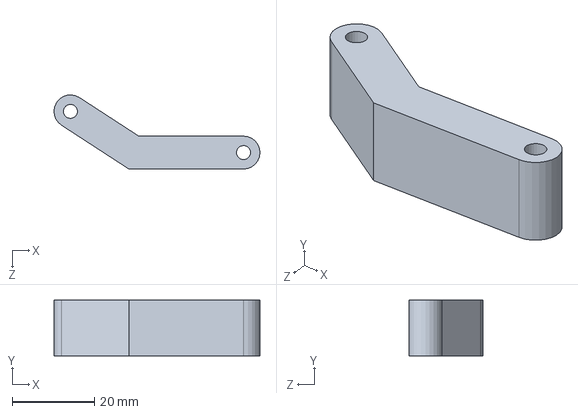
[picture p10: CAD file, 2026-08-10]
3D designs/quadruped-robot-7.snapshot.7 (1)/quadruped/legA.SLDPRT
50.0 x 13.5 x 18.0 mm

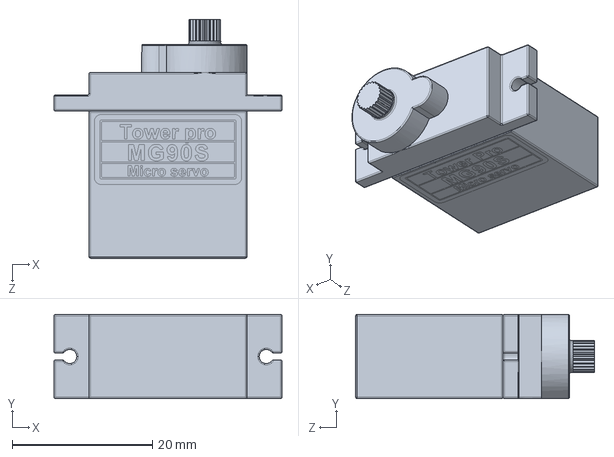
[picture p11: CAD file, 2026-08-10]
3D designs/quadruped-robot-7.snapshot.7 (1)/quadruped/mg90/MG90s_servo.SLDPRT
32.5 x 12.0 x 34.0 mm

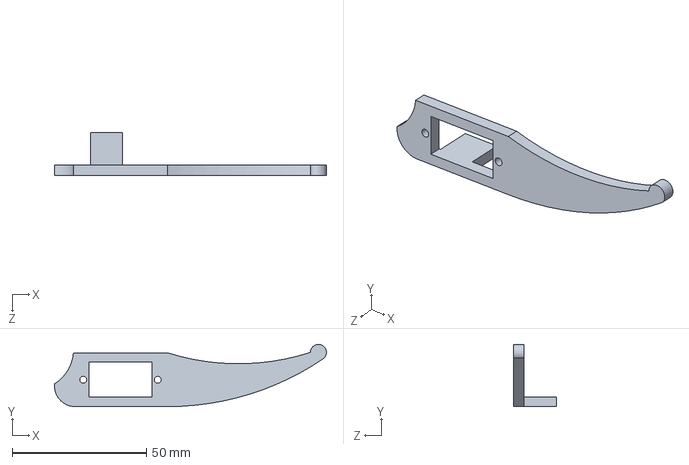
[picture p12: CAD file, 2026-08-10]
3D designs/quadruped-spider-2.snapshot.2 (1)/tibia Left.SLDPRT
101.1 x 23.1 x 16.0 mm

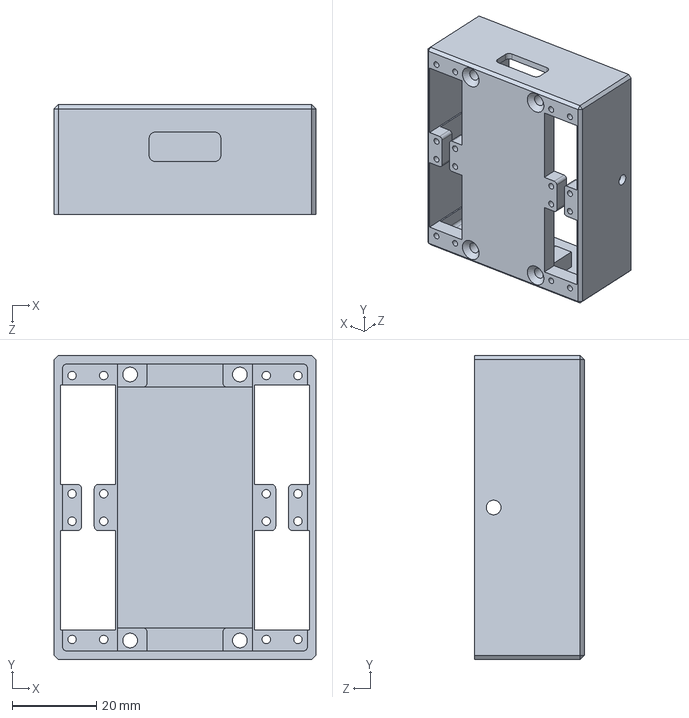
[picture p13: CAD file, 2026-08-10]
3D designs/quadruped-robot-7.snapshot.7 (1)/quadruped/bodyB.SLDPRT
62.0 x 72.0 x 26.0 mm

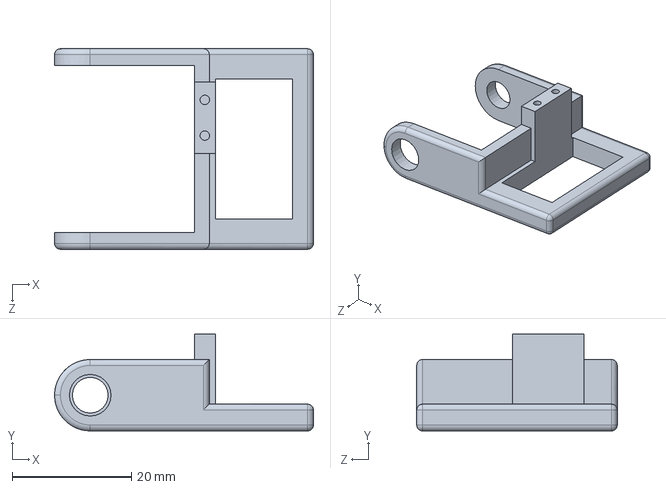
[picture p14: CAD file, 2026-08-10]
3D designs/quadruped-spider-2.snapshot.2 (1)/coxa right.SLDPRT
43.5 x 16.3 x 33.7 mm

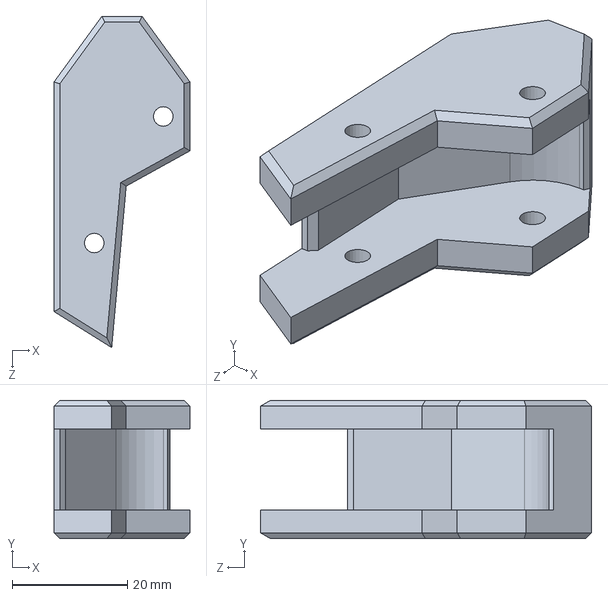
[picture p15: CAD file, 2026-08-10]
3D designs/quadruped-robot-7.snapshot.7 (1)/quadruped/foot.SLDPRT
23.6 x 24.0 x 57.6 mm

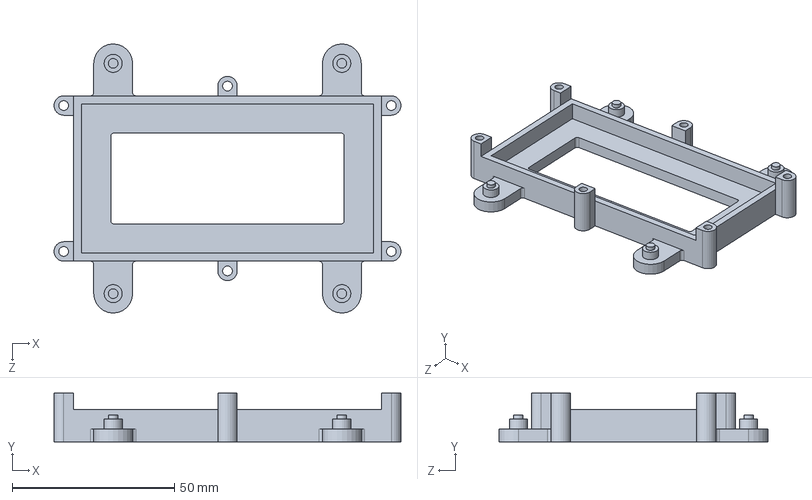
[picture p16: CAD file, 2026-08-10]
3D designs/quadruped-spider-2.snapshot.2 (1)/Base Down.SLDPRT
107.0 x 15.0 x 83.0 mm

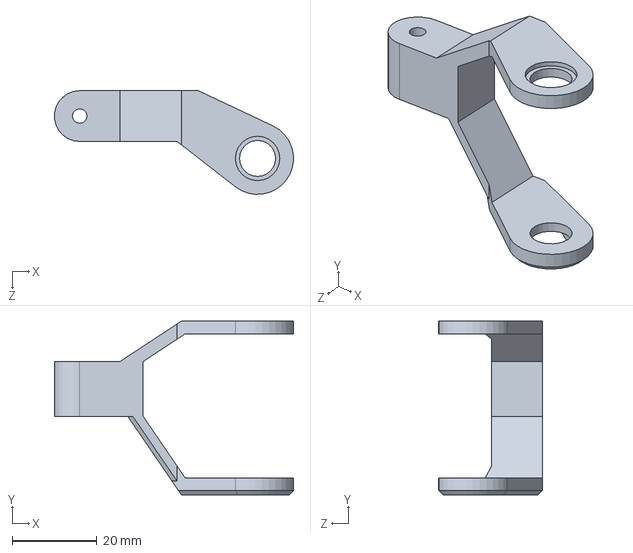
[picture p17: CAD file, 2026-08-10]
3D designs/quadruped-robot-7.snapshot.7 (1)/quadruped/rightLegB.SLDPRT
56.4 x 41.0 x 24.5 mm

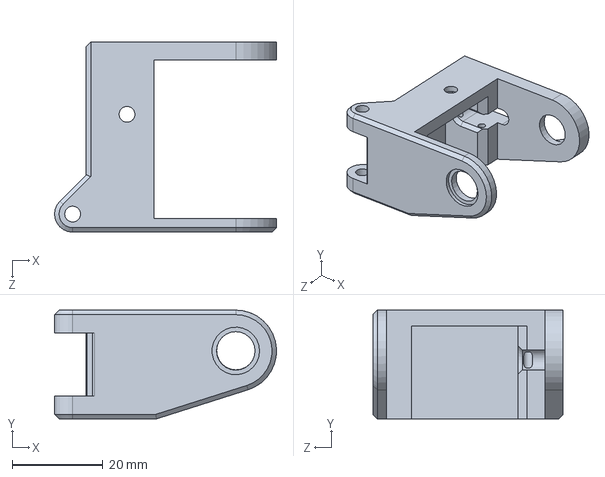
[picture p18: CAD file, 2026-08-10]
3D designs/quadruped-robot-7.snapshot.7 (1)/quadruped/rightBracket.SLDPRT
49.0 x 24.0 x 42.0 mm

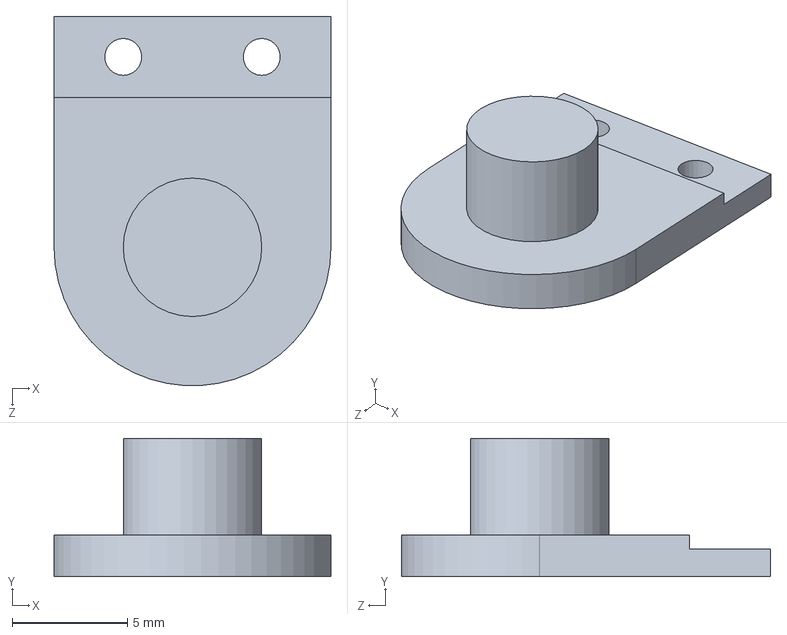
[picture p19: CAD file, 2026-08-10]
3D designs/quadruped-spider-2.snapshot.2 (1)/Hold.SLDPRT
12.0 x 6.00 x 16.0 mm

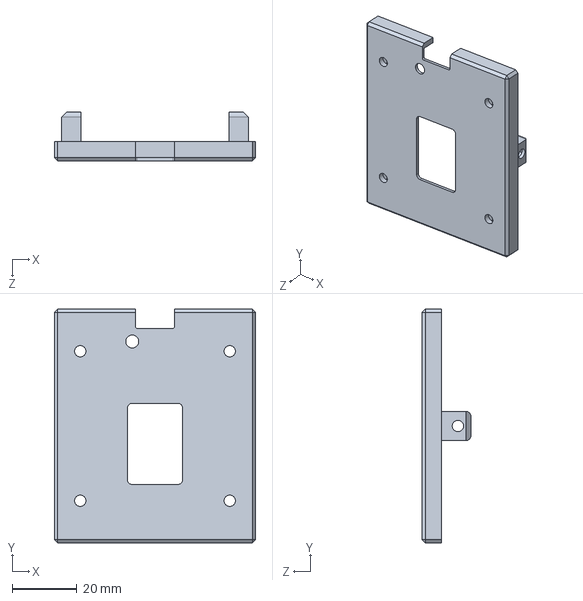
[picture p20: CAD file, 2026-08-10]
3D designs/quadruped-robot-7.snapshot.7 (1)/quadruped/bodyA.SLDPRT
62.0 x 72.0 x 15.0 mm

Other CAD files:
3D designs/quadruped-robot-7.snapshot.7 (1)/quadruped/mdoi.SLDPRT
3D designs/quadruped-spider-2.snapshot.2 (1)/coxa left.SLDPRT
3D designs/quadruped-spider-2.snapshot.2 (1)/Servo SG90.SLDPRT
3D designs/quadruped-robot-7.snapshot.7 (1)/quadruped/leftLegB.SLDPRT
3D designs/quadruped-robot-7.snapshot.7 (1)/quadruped/leftBracket.SLDPRT
3D designs/quadruped-robot-7.snapshot.7 (1)/quadruped/mg90/MG90s_servo.IGS
3D designs/quadruped-spider-2.snapshot.2 (1)/Base up.SLDPRT
3D designs/quadruped-spider-2.snapshot.2 (1)/Fumer.SLDPRT
3D designs/quadruped-spider-2.snapshot.2 (1)/tibia right.SLDPRT

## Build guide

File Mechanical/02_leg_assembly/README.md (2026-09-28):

# 02 Leg Assembly
## RUNNER-4 | 12x MG90S Metal-Gear Servos | 3-DOF per Leg

## Objective
Assemble all four 3-DOF legs using MG90S metal-gear micro-servos, with correct link lengths and PCA9685 channel assignments.

## Kinematic Structure (per leg)

```
   BODY
    |
    | 30mm  COXA  — J1 yaw:   horizontal forward/backward swing ±45°
    |               (PCA9685: CH0=FL, CH3=FR, CH6=BL, CH9=BR)
    ●  coxa pivot
    |
    | 60mm  FEMUR — J2 pitch: vertical lift/lower ±90°
    |               (PCA9685: CH1=FL, CH4=FR, CH7=BL, CH10=BR)
    ●  femur pivot
    |
    | 80mm  TIBIA — J3 pitch: knee extension ±90°
    |               (PCA9685: CH2=FL, CH5=FR, CH8=BL, CH11=BR)
    ●
   FOOT  (rubber tip contacts ground)

   Max reach from coxa pivot: 60 + 80 = 140 mm
   Min reach from coxa pivot: |60 - 80| = 20 mm
   Nominal foot depth (z):    50 mm below body centre
```

## Hardware Required Per Leg

| Part | Qty per leg | Total (4 legs) | Notes |
|---|---|---|---|
| MG90S metal-gear servo | 3 | **12** | Metal gears mandatory — plastic strips |
| Coxa bracket (PETG, 100% infill) | 1 | 4 | Servo body screwed inside |
| Femur link (PETG) | 1 | 4 | 60mm L2 |
| Tibia link (PETG) | 1 | 4 | 80mm L3, rubber foot socket at tip |
| MR83ZZ radial bearing | 1 | 4 | Opposite side of coxa servo shaft |
| M3×8 socket head | 4 | 16 | Servo to bracket |
| M3×12 socket head | 2 | 8 | Femur pivot bolt |
| M3 nylon locknut | 6 | 24 | All pivot joints |
| Silicone rubber foot cap | 1 | 4 | Tibia tip, prevents slipping |

## MG90S Servo Specifications

```
Torque:    2.2 kg·cm @ 6V  (metal gears)
Speed:     0.08 sec/60° @ 6V
Pulse:     500µs (0°) to 2400µs (180°)
Dead band: 5µs
Weight:    13.4g
```

> **Power:** Servos MUST be powered from the 6V switching BEC rail, NOT from STM32 or PCA9685 logic power. Connecting servo V+ to 3.3V logic will instantly damage the STM32.

## PCA9685 Channel Mapping

| CH | Leg | Joint | Neutral | Dir at 0° | Dir at 180° |
|----|-----|---|---|---|---|
| 0 | FL | Coxa J1 | 90° | Forward sweep | Backward |
| 1 | FL | Femur J2 | 45° | Leg down | Leg up |
| 2 | FL | Tibia J3 | 135° | Tibia folded | Tibia extended |
| 3 | FR | Coxa J1 | 90° | Backward* | Forward* |
| 4 | FR | Femur J2 | 135° | Leg up* | Leg down* |
| 5 | FR | Tibia J3 | 45° | Extended* | Folded* |
| 6 | BL | Coxa J1 | 90° | Forward sweep | Backward |
| 7 | BL | Femur J2 | 45° | Leg down | Leg up |
| 8 | BL | Tibia J3 | 135° | Tibia folded | Extended |
| 9 | BR | Coxa J1 | 90° | Backward* | Forward* |
| 10 | BR | Femur J2 | 135° | Leg up* | Leg down* |
| 11 | BR | Tibia J3 | 45° | Extended* | Folded* |

> `*` = Right-side legs (FR, BR) are physically mirrored. FR/BR femur and tibia angles = `180° − left_side_angle`.

## Assembly Steps

> **⚠️ CRITICAL: DO NOT attach servo horns until Module 06 (Zeroing). Attach horns only while servos are powered and holding 90°.**

1. Assemble coxa bracket — press MR83ZZ bearing into the bearing seat on the far side
2. Insert MG90S into coxa bracket, secure with M3×8 screws (do not overtighten — servo casing is aluminium)
3. Pivot-connect femur link to coxa bracket using M3×12 bolt + nylon locknut — should rotate freely with no stiffness
4. Pivot-connect tibia link to femur link — same M3×12 + locknut
5. Press silicone rubber cap onto tibia tip
6. Route servo cable through the coxa bracket cable channel, zip-tie to prevent snagging during leg swing

## Debugging

| Problem | Cause | Fix |
|---|---|-----|
| Joint stiff when moved by hand (servo off) | Bracket too tight / misaligned | Loosen locknut until free rotation |
| Servo hums loudly at neutral | Mechanical binding fighting servo | Check all pivot points for friction |
| Leg clicks under load | Stripped plastic gear | Replace servo — use metal gear only |
| Leg swings but no ground contact | Tibia too short / link length wrong | Verify L2=60mm L3=80mm in printed parts |
| BR leg not moving | PCA9685 channel mis-wired | Verify CH9/10/11 connectors |

---
🔙 **[Back to Mechanical](../README.md)**

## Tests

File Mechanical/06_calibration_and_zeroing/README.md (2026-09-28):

# 06 Calibration & Zeroing
## RUNNER-4 | Servo Zeroing + Software Offset Calibration

## Objective
Mechanically align all 15 servos to exactly 90° neutral, then calibrate sensor offsets via UART. This is the **single most important step** — IK math fails if servos are off-centre.

## Why Zeroing is Critical

```
The IK solver in kinematics.c assumes:
  command 90° -> physical leg segment exactly perpendicular to body

If servo horn attached 5° off-centre:
  command 90° -> physical angle is 85° or 95°
  Robot walks crooked, limps, or falls over

Example: if all 12 leg servos are 3° off:
  FR leg extends further than FL -> robot circles right
  Body pitch wrong -> IK solutions are all offset -> unstable trot
```

## Part A: Mechanical Servo Zeroing (do BEFORE attaching horns)

```
Process:
1. DO NOT attach servo horns or leg linkages yet
2. Wire all 15 servos to PCA9685 (CH0-CH14)
3. Open STM32 debug UART at 115200 baud (PA9)
4. Send command: "servo_all 90\r\n"
   -> All PCA9685 channels set to tick 307 (1500µs = 90°)
   -> All servos powered and actively holding 90°
5. While servos hold 90°, push servo spline horns onto shafts
   so that physical leg position matches your CAD reference angle
6. Immediately screw the servo horn M2.5 self-tapping screws
   (do NOT release power while screwing — servo will snap to new position)
```

### Reference Angles for Horn Attachment

| CH | Leg | Joint | Physical angle when servo at 90° |
|----|-----|---|---|
| 0 | FL | Coxa | Leg pointing straight sideways |
| 1 | FL | Femur | Femur at 45° from horizontal (partial lift) |
| 2 | FL | Tibia | Tibia extended 135° from femur axis |
| 3 | FR | Coxa | Leg pointing straight sideways (mirrored) |
| 4 | FR | Femur | Femur at 135° (180 - 45, mirrored) |
| 5 | FR | Tibia | Tibia at 45° from femur axis (mirrored) |
| 6 | BL | Coxa | Same as FL |
| 7 | BL | Femur | Same as FL |
| 8 | BL | Tibia | Same as FL |
| 9 | BR | Coxa | Same as FR |
| 10 | BR | Femur | Same as FR |
| 11 | BR | Tibia | Same as FR |
| 12 | Arm | Pitch | Arm pointing straight up (vertical HOME) |
| 13 | Gripper | Open/Close | Fingers at 60° open position |
| 14 | Gate | Lock/Open | Gate plate fully closed (locked) |

## Part B: Software Trim Offsets

Because servo splines have discrete teeth, mechanical zeroing is rarely perfect. Create a `calibration.h` offset file:

```c
/* firmware/Drivers/PCA9685/calibration.h */
#ifndef CALIBRATION_H
#define CALIBRATION_H

/**
 * Servo trim offsets in degrees.
 * Positive = servo physically reads too low (add offset to correct).
 * Negative = servo physically reads too high.
 *
 * Measure: command 90°, measure actual physical angle with protractor.
 * offset[i] = 90 - measured_angle
 *
 * Apply in pca9685.c:
 *   corrected_angle = commanded_angle + servo_trim_offsets[ch]
 */
const float servo_trim_offsets[15] = {
    /*CH0  FL Coxa  */ 0.0f,
    /*CH1  FL Femur */ 0.0f,
    /*CH2  FL Tibia */ 0.0f,
    /*CH3  FR Coxa  */ 0.0f,
    /*CH4  FR Femur */ 0.0f,
    /*CH5  FR Tibia */ 0.0f,
    /*CH6  BL Coxa  */ 0.0f,
    /*CH7  BL Femur */ 0.0f,
    /*CH8  BL Tibia */ 0.0f,
    /*CH9  BR Coxa  */ 0.0f,
    /*CH10 BR Femur */ 0.0f,
    /*CH11 BR Tibia */ 0.0f,
    /*CH12 Arm      */ 0.0f,
    /*CH13 Gripper  */ 0.0f,
    /*CH14 Gate     */ 0.0f,
};

#endif
```

### How to Measure and Fill the Offset Array

```
For each channel CH0 to CH14:
  1. Send UART command: "servo <CH> 90\r\n"
  2. With a digital protractor / angle gauge, measure actual physical angle
  3. offset = 90 - measured_angle
     (e.g., if servo reads 87° when commanded 90°: offset = +3)
  4. Fill calibration.h with measured offsets
  5. Rebuild and flash firmware

Repeat until all channels read 90° ± 1° when commanded 90°.
```

## Part C: IR Line Array Calibration (via UART)

```
1. Place all 9 TCRT5000 sensors over WHITE surface (arena white floor):
   UART: "la_cal white\r\n"
   -> Captures and stores cal_white[9] to STM32 Flash

2. Place all 9 sensors over BLACK surface (black line tape):
   UART: "la_cal black\r\n"
   -> Captures and stores cal_black[9] to Flash

3. Verify calibration:
   UART: "la_test\r\n"
   -> Returns line_val[0..8] on Serial
   Black surface: all values < 0.10
   White line:    active sensors  > 0.80
   Centre (S5):   centroid ~ 4.0 ± 0.3
```

## Part D: ToF Sensor Verification

```
1. UART: "tof_scan\r\n"
   -> Must report: FRONT=0x30 OK, LEFT=0x31 OK, RIGHT=0x32 OK

2. Place flat wall 200mm from front:
   UART: "tof_read\r\n"
   -> FRONT should read 195-205mm

3. Remove left wall:
   -> tof[LEFT].is_gap should become TRUE after 3 readings

4. Place robot in corridor (150mm walls each side):
   TOF_WallFollowError() should return ≈ 0 ± 10mm
```

## Part E: IMU Verification

```
1. Place robot on known-flat surface:
   UART: "imu_read\r\n"
   -> pitch_deg = 0 ± 3°
   -> roll_deg  = 0 ± 3°

If outside tolerance:
   a) Check MPU6050 is mechanically level (use a bubble level)
   b) Wait 5 seconds after power-on before reading (gyro warm-up)
   c) Add CF_ALPHA bias correction in mpu6050.c if systematic drift
```

## Full Calibration Checklist

```
[ ] All 15 servo horns attached at correct 90° reference angles
[ ] calibration.h filled with measured trim offsets for CH0-CH14
[ ] la_cal white  -> saved to Flash
[ ] la_cal black  -> saved to Flash
[ ] IR test: black < 0.10, white > 0.80, centroid ±0.3
[ ] ToF scan: all three sensors found (0x30, 0x31, 0x32)
[ ] ToF distance: 200mm wall reads 195-205mm
[ ] IMU: pitch=0 ±3° and roll=0 ±3° on flat surface
[ ] Arm HOME (90°): sensor vertical, no chassis contact
[ ] Gripper OPEN (60°): fingers clear of 40mm ball
[ ] Gate LOCKED (0°): plate fully sealed, no ball gap
```

---
🔙 **[Back to Mechanical](../README.md)**

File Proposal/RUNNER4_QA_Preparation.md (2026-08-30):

# RUNNER-4 — Q&A Preparation (30 Questions + Answers)

---

### 1. Why did you choose a quadruped instead of a hexapod or biped?

A quadruped uses 12 servos versus 18 for a hexapod, saving 80g in servo weight, reducing power draw, and simplifying the control software. A hexapod would be difficult to fit within the 250 mm footprint with adequate leg workspace. A biped is impractical — it requires dynamic balance control far beyond what MG90S servos and a simple IMU can achieve. The quadruped with crawl gait (3 feet always on ground) provides guaranteed static stability with the minimum servo count.

### 2. Why 12 DOF? Why not 8 DOF (2 per leg)?

Three DOF per leg (coxa yaw, femur pitch, tibia pitch) provides full 3D foot positioning (x, y, z). A 2-DOF leg cannot produce lateral movement, body roll compensation, or adjust stride width — all critical for wall following, turning, and pushing stability. The third joint (coxa) also enables the robot to tuck its legs inward to meet the 250 mm footprint at the starting position.

### 3. Can MG90S servos actually support this robot?

At 6V, MG90S provides 2.2 kg·cm torque. Our estimated robot mass is ~550g. During crawl gait (3 stance legs), each femur joint bears approximately 0.77 kg·cm static torque. With a 2× dynamic safety factor, the requirement is ~1.53 kg·cm — within the 2.2 kg·cm rating with a 1.4× margin. This is tight but achievable if we keep mass under 550g and use crawl gait exclusively. We will validate this with a physical single-leg test before full assembly.

### 4. What if MG90S is not enough?

Our backup plan is a hybrid configuration: upgrade the 8 femur and tibia servos to MG996R (10 kg·cm, 55g each) while keeping MG90S for the 4 low-load coxa joints. This adds ~340g but provides a 5× torque margin. The PCA9685 and wiring support either servo — it's a drop-in swap.

### 5. Why one PCA9685 instead of two?

We use 15 of 16 channels (12 legs + 3 mechanism servos). One PCA9685 is sufficient. A second board would add 8g, an extra I2C address, and unnecessary complexity with zero benefit.

### 6. Why STM32F401 and not an Arduino?

The STM32F401 runs at 84 MHz with hardware floating-point (Cortex-M4F), enabling real-time IK computation for 4 legs and IMU sensor fusion within a 20ms control loop. An Arduino Uno (16 MHz, no FPU) cannot compute 12 joint angles plus IMU filtering at 50 Hz. The STM32 also provides multiple I2C and UART peripherals needed for simultaneous PCA9685, IMU, ToF, and Raspberry Pi communication.

### 7. Why Raspberry Pi 4 instead of Pi Zero 2 W?

The Pi Zero 2 W achieves only 8–12 FPS for our OpenCV pipeline (HSV + contours + centroid at 640×480). This is too slow for responsive line following. The Pi 4B provides 25–35 FPS with comfortable headroom. The weight penalty (37g extra) is acceptable. The Pi 4 also has a dedicated hardware UART (Pi Zero shares UART with Bluetooth) and USB ports for debugging.

### 8. Why not Raspberry Pi 5?

Pi 5 draws 3.5A peak (vs 2.5A for Pi 4) and requires active cooling — adding a fan increases weight, complexity, and failure risk. Our vision pipeline runs comfortably on Pi 4 at 25+ FPS. The Pi 5's extra performance provides no benefit for this competition while increasing power consumption and heat.

### 9. Why a camera instead of IR sensors for line following?

A single camera replaces three types of sensors: IR line sensors (line following), colour sensors (ball colour detection), and dedicated ball detectors. This reduces wiring, weight, and sensor integration complexity. The camera also provides richer information — junction detection, obstacle recognition, and colour sorting — that discrete sensors cannot. The trade-off is higher software complexity and power consumption, but the Pi 4B handles this well.

### 10. How do you detect the ball's colour?

We convert camera frames to HSV colour space and apply separate masks for Red (H=0–10 and 165–179), Green (H=40–85), and Blue (H=95–135), all with high saturation (S>100) and moderate value (V>70). We count pixels in each mask and classify the colour with the highest qualifying count, requiring 2× dominance over the next-highest colour for confident classification.

### 11. How do you handle the ball being on a 5 cm pedestal?

The ball sits 50 mm above the ground. A floor-level scoop or funnel cannot reach it. Our 2-servo arm has a pitch joint that lowers the gripper from body level down to pedestal height. The arm reach is ~50–60 mm from pivot to gripper, sufficient to reach the ball. The gripper opens to >40 mm to accommodate the 40 mm diameter ball.

### 12. How do you store the ball securely?

After grasping, the arm lifts the ball over the body and drops it into an internal belly compartment with an opening at the top. A servo-controlled gate locks the ball inside. The compartment walls are fully enclosed — the ball cannot escape during walking, turning, wall following, or pushing.

### 13. How do you release the ball in Subtask 4?

The compartment has a servo-operated gate at the bottom. To release, the robot positions over the target colour zone, opens the gate, and the ball drops by gravity. The same servo that locks the gate during storage opens it for release — no additional actuator.

### 14. Why a passive bumper instead of a robotic arm for pushing?

A passive bumper has zero additional actuators, zero extra weight, zero additional failure modes, and zero extra power consumption. The quadruped's legs provide the pushing force through the crawl gait — the bumper simply transmits this force to the obstacle. A robotic arm for pushing would add complexity without benefit.

### 15. How do you stabilize the robot during pushing?

Before pushing, the robot lowers its body height from ~70 mm to ~45 mm (reducing the tipping moment), widens its leg stance (increasing the support polygon), and switches to slow crawl gait at 50 mm/s. The IMU continuously monitors pitch — if pitch exceeds 15°, the controller reduces push speed to prevent tipping.

### 16. How do 3 ToF sensors handle wall following with gaps?

We use a gap rejection filter. During normal wall following, the lateral error is e = d_left − d_right. When a gap appears (one sensor reads >400 mm), the robot switches to single-wall following using only the solid wall sensor. The filter requires 3 consecutive out-of-range readings before switching, preventing noise-triggered false gaps. When both walls return, normal dual-wall centering resumes.

### 17. What if both walls have gaps simultaneously?

If both sensors read >400 mm simultaneously, the robot holds its current heading using the IMU gyroscope and continues straight until at least one wall reappears. This is a valid scenario because the competition rules indicate gaps may appear on either side.

### 18. How do you guarantee the robot is fully autonomous?

No wireless modules are active. Wi-Fi and Bluetooth are disabled at the OS level (`dtoverlay=disable-wifi` and `dtoverlay=disable-bt` in `/boot/config.txt`). The Pi has no Wi-Fi or Bluetooth functionality during operation. All processing occurs onboard. The robot uses only UART (wired, internal) between Pi and STM32. There is no laptop, phone, or remote controller dependency.

### 19. How do you meet the 250 × 250 mm footprint?

The body is designed at approximately 160 × 140 mm. Before competition, we measure the standing footprint using a jig/template. The coxa angles at the starting position are adjusted to keep all feet within 250 × 250 mm. During the run, the legs extend beyond this footprint during walking, which the rules explicitly permit ("Expansion during the run is allowed").

### 20. What is your biggest risk?

MG90S servo torque margin. At 1.4× safety margin for crawl gait, there is limited headroom for mechanical imperfections, heavier-than-estimated 3D prints, or higher friction conditions. Mitigation: keep mass under 550g, validate with a physical leg test early, and have MG996R hybrid as a defined backup path.

### 21. What happens if the camera fails mid-run?

The STM32 detects UART command timeout (no commands from Pi for 500 ms) and enters SAFE_STOP mode — all servos hold current position. The Pi attempts to reinitialise the camera. If vision is permanently lost, the robot can switch to ToF-only degraded navigation for corridor tasks (wall following still works). Ball and colour tasks would fail without camera.

### 22. What happens if a servo stalls?

The STM32 monitors IMU data — if servo commands are issued but no body movement is detected (no angular change in IMU), a stall is suspected. The controller reduces the gait amplitude, retries the movement, and if the stall persists, enters SAFE_STOP with a red status LED.

### 23. What happens if the battery voltage drops?

The STM32 monitors battery voltage via ADC voltage divider. At 6.8V (3.4V/cell), the status LED flashes red and servo speed is reduced. At 6.4V (3.2V/cell), the robot enters SAFE_STOP to prevent LiPo damage. Expected runtime is ~24 minutes with 1300mAh — well above the 15-minute competition limit.

### 24. How do you calibrate within 2 minutes?

Calibration is mostly pre-loaded in firmware (servo trim offsets, HSV thresholds, ToF offsets). During the 2-minute prep:
1. Power on → automatic self-test (3 seconds)
2. Status LED confirms ready (green = all OK)
3. Place robot on start line
4. Minor sensor adjustments only if needed (ToF angle)
No code changes are made at competition.

### 25. How do you handle a restart?

The state machine has a defined START state. On restart, the robot returns to START and begins from Subtask 1. The `stored_ball_color` variable is reset. The timer continues running (not paused). Up to 3 restarts are allowed within 10 minutes.

### 26. Why crawl gait and not trot?

Trot gait requires each femur servo to support 50% of robot weight (2 legs in stance). At our estimated mass, this demands 2.3 kg·cm — exceeding the MG90S 2.2 kg·cm rating. Crawl gait requires only 1.53 kg·cm per femur (3 legs in stance), which is within the servo's capability. Crawl is slower but the competition evaluates completion, not speed.

### 27. How does the colour junction work in Subtask 4?

The camera detects coloured lines emerging from the main white line. The robot recalls `stored_ball_color` from memory (stored in Subtask 1). It identifies the matching coloured branch using HSV segmentation (same thresholds used for ball detection). The robot turns onto the matching branch, navigates to the drop zone, releases the ball, reverses back to the main line, and continues to the finish.

### 28. What is your power architecture?

2S LiPo (7.4V) → toggle switch → 10A fuse → three isolated rails:
1. **5V/15A BEC** → PCA9685 V+ → all 15 servos (with 4700µF bulk capacitor)
2. **5V/3A buck regulator** → Raspberry Pi 4B (via GPIO 5V pins)
3. **STM32 VBUS** → onboard 3.3V LDO → STM32 logic + MPU6050 + 3× VL53L0X

Servo power NEVER flows through the STM32 or PCA9685 logic supply.

### 29. What is your backup plan overall?

- **Servo failure**: MG996R hybrid swap (pre-designed)
- **Camera failure**: ToF-only degraded mode (wall following still works)
- **Pi crash**: STM32 watchdog → SAFE_STOP; use restart allowance
- **Ball pickup failure**: Retry once; skip ball (partial score, continue other tasks)
- **Competition restart**: 3 restarts available within 10 minutes

### 30. How do you verify ball release in Subtask 4?

After opening the compartment gate, the camera checks a downward ROI to see if the ball is visible on the ground beneath the robot. If the ball is not detected within 3 seconds, the gate opens/closes again and the body tilts forward to assist gravity. If still unsuccessful after 2 attempts, the robot logs the failure and continues to the finish.

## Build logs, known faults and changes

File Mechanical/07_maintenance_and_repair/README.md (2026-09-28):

# 07 Maintenance & Repair
## RUNNER-4 | Pre-Run Checklists + Common Hardware Failures

## Objective
Diagnose physical hardware failures quickly during testing, and ensure the robot is competition-ready before every arena run.

## Common Hardware Failures

### 1. Stripped MG90S Servo Gears

| Field | Detail |
|---|---|
| **Symptom** | Leg clicks loudly under load, sags when commanded, moves freely when powered off |
| **Cause** | Impact with arena wall, leg getting stuck, or sustained stall (gait programming error) |
| **Diagnosis** | Hold servo body, gently rotate output shaft by hand — feel for grinding/loose play |
| **Fix** | Replace entire servo (gear sets for MG90S are available but time-consuming to swap under competition pressure) |
| **Prevention** | Add soft limits in firmware: clamp all joint angles to [10°, 170°] to prevent stall at extremes |

### 2. Loose Leg Linkages

| Field | Detail |
|---|---|
| **Symptom** | Robot wobbles, foot placement inaccurate by 10–20mm, IK appears correct but gait drifts |
| **Cause** | M3 locknuts vibrating loose over time (arena floor vibration + servo shock loads) |
| **Diagnosis** | Grab each femur/tibia link and wiggle — there should be zero rotational play |
| **Fix** | Apply one drop of **Blue Loctite 243** to each metal-to-metal pivot screw. Re-tighten locknut while Loctite is wet. Wait 30min before powering servos. **Do NOT use Loctite on plastic holes** — it dissolves PETG. |

### 3. Servo Jitter / Twitching at Neutral

| Field | Detail |
|---|---|
| **Symptom** | Servos vibrate or twitch rapidly when robot is standing still (Vx=0, Wz=0) |
| **Cause A** | Ground loop between BEC GND, STM32 GND, and PCA9685 GND — star ground not connected |
| **Cause B** | Servo rail voltage ripple — 470µF capacitor missing from 6V BEC rail |
| **Cause C** | I2C pull-up resistors missing — PCA9685 receiving corrupted commands |
| **Fix** | Check star ground (Module 05). Add 470µF electrolytic cap on servo rail. Verify 4.7kΩ pull-ups on I2C1. |

### 4. I2C Bus Failure (sensor offline)

| Field | Detail |
|---|---|
| **Symptom** | UART shows sensor not found, state machine enters SAFE_STOP |
| **Cause** | Loose DuPont connector on SDA/SCL, or missing pull-up resistor |
| **Diagnosis** | `tof_scan\r\n` returns FAIL for one sensor. I2C bus ACK failure on STM32 HAL. |
| **Fix** | Hot-glue all I2C connectors. Verify 4.7kΩ pull-up to 3.3V on both I2C1 and I2C2. Verify XSHUT pins (PB12/13/14) configured as GPIO Output in CubeMX. |

### 5. Line Array Reads All White or All Black

| Field | Detail |
|---|---|
| **Symptom** | `la_test\r\n` returns all sensors > 0.9 or all < 0.1 regardless of surface |
| **Cause A** | Calibration data lost (Flash not programmed) |
| **Cause B** | Sensor PCB height wrong (not at 5mm from floor) |
| **Cause C** | ADC DMA not started (`LA_Init()` not called in `App_Init()`) |
| **Fix** | Re-run `la_cal white` then `la_cal black`. Verify sensor bar height. Check `HAL_ADC_Start_DMA()` call. |

### 6. Robot Walks in Circles / Drifts

| Field | Detail |
|---|---|
| **Symptom** | Robot veers left or right on straight Vx command |
| **Cause** | Servo trim offsets not calibrated — one side of legs has systematic angle error |
| **Fix** | Re-do Module 06 calibration. Fill `calibration.h` with measured offsets for all 12 leg channels. |

### 7. Arm Drops Under Ball Weight

| Field | Detail |
|---|---|
| **Symptom** | CH12 arm cannot hold horizontal position with ball in gripper |
| **Cause** | MG90S torque margin at 0.94x — marginal at full arm extension |
| **Fix Option A** | Shorten arm link from 65mm to 50mm to reduce torque requirement |
| **Fix Option B** | Upgrade CH12 to MG996R (10 kg·cm) for 4.3x margin |

## Pre-Run Competition Checklist

Run this checklist before placing robot on the starting line:

### Mechanical
```
[ ] All 12 leg locknuts checked for tightness (attempt to rotate by hand — zero play)
[ ] Rubber feet on all 4 tibias — not worn through
[ ] Arm link M2 screws tight — TCS34725 sensor firmly mounted
[ ] Gripper fingers intact — foam/rubber lining present
[ ] Gate plate swings freely — hinge not binding
[ ] No servo horn screws missing
```

### Electrical
```
[ ] Battery voltage: > 7.4V (2S) or > 11.1V (3S)
[ ] Kill switch functional — cycle ON/OFF
[ ] 6V BEC output: 6.0V ± 0.1V (measure with multimeter)
[ ] 3.3V logic rail: 3.30V ± 0.05V
[ ] All I2C connector joints hot-glued or zip-tied
[ ] No bare wire shorts visible
```

### Firmware & Sensors
```
[ ] UART connect: SM boots to state 0→1→2 correctly
[ ] tof_scan -> FRONT OK, LEFT OK, RIGHT OK
[ ] imu_read -> |pitch| < 3° and |roll| < 3° on flat surface
[ ] la_test  -> sensors respond correctly to white and black
[ ] servo_all 90 -> all 15 servos reach neutral without jitter
[ ] Press start button (PC13) -> SM transitions to T1_LINE_FOLLOW (state 3)
[ ] Vx=0 Wz=0 command -> robot stands level, all 4 feet grounded evenly
```

### Arena Walk Test (do 2 minutes before competition run)
```
[ ] Walk forward 1m at Vx=60 mm/s -> straight, no drift
[ ] Arm cycle: HOME -> MODE_A -> CLOSE -> HOME
[ ] Gate cycle: LOCKED -> OPEN -> LOCKED
[ ] Colour sensor test: red/green/blue ball under competition lighting
[ ] ToF corridor test: wall-follow maintains 150mm ± 20mm
```

## Quick-Swap Spares to Carry

| Item | Qty to carry | Why |
|---|---|-----|
| MG90S servo (spare) | 3 | Gear strip under stall |
| M3×12 locknuts | 10 | Vibrate loose |
| Servo horn screws M2.5 | 10 | Fall out during impact |
| Blue Loctite 243 | 1 tube | Preventive application |
| DuPont 3-pin servo extension | 3 | Connector failure |
| USB to UART (CH340) | 1 | Debug during arena |

---
🔙 **[Back to Mechanical](../README.md)**

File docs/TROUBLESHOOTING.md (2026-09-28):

# TROUBLESHOOTING GUIDE

## 1. Overview
This guide covers common issues encountered during development and testing of the RUNNER-4 embedded system. All troubleshooting uses a debug UART (USART1, PA9 TX, 115200 baud) and ST-Link SWD debugger during development.

> [!WARNING]
> The debug UART cable MUST be physically disconnected before competition. The competition rules prohibit any external wired communication during the run.

---

## 2. STM32 Boot & General Issues

| Symptom | Likely Cause | Fix |
|---|---|-----|
| STM32 not powering on | 3.3V LDO missing; USB not connected | Verify STM32 VBUS pin has 5V; check LDO output with multimeter |
| Firmware not loading | ST-Link not detected | Check SWD wires (SWDIO, SWDCLK, GND); press BOOT0 + RESET then release RESET |
| Loop runs at wrong speed | TIM2 misconfigured | Verify TIM2 period = `(APB1_clock / prescaler) - 1` gives 50Hz; check with oscilloscope or DWT |
| I2C devices not found | Wrong bus or pull-up | Run I2C address scan; verify PB6/PB7 (I2C1) and PB10/PB3 (I2C2) have 4.7kΩ pull-ups to 3.3V |

---

## 3. 9-Channel TCRT5000 IR Line Array (ADC1 DMA)

### Sensor Calibration Procedure
1. Power on STM32 with debug UART connected.
2. Place array over **plain black surface**. Send `la_cal black\r\n` via UART.
   - All 9 normalised values should approach 0.0. If any stay above 0.1, check mounting height (should be 5mm).
3. Place array over **30mm white matte paper**. Send `la_cal white\r\n` via UART.
   - Active sensors over white should return normalised value > 0.8.
4. Send `la_test\r\n`. When centred on line, centroid ≈ **4.0**. error ≈ 0.0.
5. Slide array slowly sideways — verify smooth centroid transition, no discontinuities.

### Common Line Array Issues

| Symptom | Likely Cause | Fix |
|---|---|-----|
| All sensors return same high value | ADC DMA not started — `LA_Init()` not called | Verify `HAL_ADC_Start_DMA()` called in `App_Init()` |
| All sensors return same low value | 10kΩ pull-ups missing or ADC reference wrong | Check pull-ups on PA0-PA7, PB0; verify VREF=3.3V |
| Erratic readings at line edge | Sensor mounted too high (>8mm) or too low (<3mm) | Adjust bracket to exactly 5mm height |
| Line lost mid-run | Line array vibrating loose | Tighten bracket screws; add vibration-damping foam |
| `la_cal` not saving | Flash write failed | Verify Flash sector not write-protected; re-flash |
| S9 (rightmost) not responding | PB0 not in ADC1 scan sequence in CubeMX | Re-check CubeMX: ADC1 regular channel 8 = PB0 IN8 |
| Centroid stuck at 0 or 7 | All sensors on one side active | Robot is too far off-line; PD gain too low → increase Kp |
| False intersection triggers | Wide curve activating 6+ sensors | Raise intersection threshold from 6 to 7 sensors |

---

## 4. TCS34725 Colour Sensor

### Colour Classification Calibration (2-Minute Pre-Competition Procedure)
1. Connect debug UART; power robot.
2. Turn on LED (PC0 HIGH).
3. Hold arm in **MODE A** position (0°, ball-reading angle).
4. Hold a **RED coloured object** 2cm from sensor. Log `r_n, g_n, b_n` values from UART.
   - Expected: `r_n > 0.40`, `r_n >> g_n`, `r_n >> b_n`.
5. Repeat with **GREEN** object: expected `g_n > 0.35`, dominant.
6. Repeat with **BLUE** object: expected `b_n > 0.30`, dominant.
7. If ratios are borderline: adjust gain constant in firmware (`TCS34725_GAIN_16X` instead of `4X`) and reflash.

### Arm Position Calibration
1. Set arm servo to `MODE A` PWM constant.
2. Verify arm is horizontal (use a spirit level or angle gauge).
3. Verify sensor tip is ~5cm above ground (matches ball pedestal height).
4. Set arm servo to `MODE B` PWM constant.
5. Verify arm points ~70° below horizontal.
6. Hold sensor 2cm above a colour line on the floor → verify reading.

### Common TCS34725 Issues

| Symptom | Likely Cause | Fix |
|---|---|-----|
| Always returns `COLOR_UNKNOWN` | Sensor too far from target or wrong gain | Move arm closer; increase gain to 16× |
| Wrong colour classified | Arena lighting interfering | Turn LED ON (PC0 HIGH); increase integration time; shroud sensor |
| I2C NACK on address 0x29 | Address conflict with VL53L0X (wrong bus) | Verify TCS34725 is on I2C1 and VL53L0X on I2C2 |
| Reading blocks control loop | Blocking I2C read inside 20ms loop | Implement non-blocking: start integration, poll AVALID bit on next cycles |
| Colour flickers between RED/UNKNOWN | Too close to ball edge | Ensure arm is fully lowered to pedestal height before reading |

---

## 5. VL53L0X Time-of-Flight Sensors

| Symptom | Likely Cause | Fix |
|---|---|-----|
| All 3 ToF at same address 0x29 | XSHUT remap failed | Verify PB12/13/14 are configured as GPIO output; step through remap procedure with `HAL_Delay` |
| ToF reads 0 or 8191 | Sensor initialisation failed | Add 10ms delay after XSHUT release before sending init command |
| Erratic distance readings | Infrared cross-talk between sensors | Separate sensors physically; use median filter (5 samples) |

---

## 6. Mission State Machine

### Debug UART State Trace
Enable state transition logging during development:
```c
// In state_machine.c:
void StateMachine_Transition(State_t new_state) {
    printf("[SM] %s → %s\r\n", state_names[current_state], state_names[new_state]);
    current_state = new_state;
}
```
This allows tracing the full mission flow via a serial terminal (disable before competition).

### Flash EEPROM — Ball Colour Persistence Debug
To verify Flash write/read:
```c
// Test sequence:
Flash_StoreBallColor(COLOR_RED);
HAL_NVIC_SystemReset();  // Simulate restart
// On next boot:
uint8_t c = Flash_ReadBallColor();
printf("Recalled: %d (expect 1=RED)\r\n", c);
```
If value is `0xFF`, the Flash write failed — check sector erase + program sequence.

---

## 7. Power & Servo Issues

| Symptom | Likely Cause | Fix |
|---|---|-----|
| Servos twitch randomly | Servo rail brownout from current spike | Add 4700µF cap across PCA9685 V+/GND; check BEC rating ≥15A |
| STM32 resets when servos move | Shared power rail | Verify STM32 powered from separate 5V buck, not BEC |
| Servo jitter on one channel | Loose connector or wrong PWM value | Re-seat connector; verify PWM tick calculation (50Hz, 4096 ticks = 20ms) |
| Robot collapses when lifting | MG90S torque insufficient | Verify 6V supply; reduce mass; check for binding in joint |

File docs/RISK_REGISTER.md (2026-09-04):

# RISK REGISTER

## FMEA & Risk Analysis

| Risk | Domain | Probability | Impact | Detection | Mitigation | Recovery | Owner | Status |
|---|---|---|---|---|---|---|---|---|
| **Servo Brownout** | Power | High | Critical | STM32 / robot collapses mid-walk | Dedicated 5V/15A BEC for servos; separate 3.3V LDO for logic; 4700µF cap on servo rail | Reboot robot; ensure battery fully charged | Team B | In Progress |
| **Ground Loop Issue** | Power | Med | High | Erroneous sensor readings, I2C errors | Star grounding: all GNDs (BEC, LDO, STM32, sensors) to single point | Physically rewire | Team B | Open |
| **IR Array Ambient Light** | Sensors | Med | Med | Wrong centroid reading; false HIGH on black surface | Mount 5–8mm above floor; use digital threshold (not analog); adjust pots pre-competition | Re-tune threshold potentiometers | Team B | Open |
| **TCS34725 Ambient Light Wash** | Sensors | Med | High | UNKNOWN colour classification despite correct target | Use built-in LED illuminator (PC0 HIGH); 4× gain; 50ms integration; shroud sensor | Increase gain to 16× in 2-min prep; adjust arm angle | Team A | Open |
| **Intersection False Positive** | Navigation | Low | Med | Robot turns at wrong location mid-grid | Require ≥6 sensors for ≥3 consecutive cycles (60ms minimum) | Tighten to ≥7 sensors if needed after testing | Team A | Open |
| **Colour Memory Lost on Restart** | Firmware | Low | Critical | Robot reaches Task 4 with no stored colour → SAFE_STOP | Write `stored_ball_color` to STM32 Flash after Task 1 ID; read on boot | Flash read on restart; if 0xFF (blank), re-enter TASK1_COLOR_ID | Team B | Open |
| **STM32 Loop Timing Overflow** | Firmware | Low | High | 50Hz loop exceeds 20ms; servo jitter or missed cycles | Profile with DWT cycle counter; TCS34725 reads are non-blocking; ToF reads staggered | Reduce I2C clock retries; skip ToF alternate cycles | Team B | Open |
| **Gait Instability / Falling** | Mech | Med | High | Robot tips over while raising a leg | Static crawl gait keeps CoG within support polygon; mass <550g | IMU detects tilt >30° → emergency stop; competition restart | Team C | Open |
| **Gripper Malfunction** | Mech | Low | High | Ball slips during transit | Rubberised grip pads; servo maintains holding torque | Retry once; skip if persistent | Team C | Open |
| **Block Pushing Failure** | Mech | Low | Med | Robot lacks torque to push obstacle | Passive bumper maximises contact area; low body stance + wide stance during push | Reverse; retry with momentum | Team C | Open |
| **MG90S Torque Insufficient** | Mech | High | Critical | Robot collapses under its own weight in crawl | Mass strictly <550g; 6V servo supply; crawl only | Upgrade femur/tibia to MG996R hybrid | Team C | Open |
| **TCS34725 Wrong Arm Angle** | Mech/FW | Med | High | Sensor too far from target; UNKNOWN reading | Pre-calibrate MODE A (0°) and MODE B (−70°) PWM constants; verify before competition | Manually adjust arm angle in 2-min prep window | Team A | Open |
| **Line Array Dirt/Contamination** | Sensors | Med | Med | Wrong centroid or line-lost false trigger | Clean sensors with dry cloth before each run | Re-clean; re-check threshold | Team B | Open |
| **I2C Bus Hang (any device)** | Firmware | Low | High | STM32 HAL I2C timeout flag; loop stalls | Auto re-init I2C peripheral on timeout flag | If persistent: power-cycle sensors | Team B | Open |

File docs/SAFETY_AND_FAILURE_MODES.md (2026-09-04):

# SAFETY AND FAILURE MODES

## 1. Overview
The RUNNER-4 relies on a single STM32F411CEU6 for all control. Robust failure detection and safe recovery must be built into the firmware to protect the robot, arena, and competition score.

## 2. Hardware Safety

| Mechanism | Implementation |
|---|---|
| **Kill Switch** | Physical latching switch on main battery positive wire (rated ≥15A). Immediately cuts all power including servos. |
| **Fuse** | 10A automotive blade fuse between battery and BEC. Protects against servo stall shorting. |
| **Battery Voltage Monitor** | STM32 ADC (PC1) reads battery voltage via resistor divider. Software alert at <6.8V; halt at <6.4V. |
| **Decoupling Capacitor** | 4700µF electrolytic cap across PCA9685 V+ and GND terminals to absorb servo current spikes. |

## 3. Software Failsafes (STM32 Firmware)

### Excessive Tilt (IMU)
```c
// In Safety_Check(), called every 20ms:
if (fabsf(pitch_deg) > 30.0f || fabsf(roll_deg) > 30.0f) {
    PCA9685_AllServosDisable();   // Zero torque on all channels
    StateMachine_Transition(STATE_SAFE_STOP);
}
```
- **Trigger**: Body pitch or roll exceeds 30° (robot is falling)
- **Response**: All servo PWM disabled immediately → robot falls safely with zero additional motion
- **Recovery**: Manual restart (up to 3 competition restarts allowed)

### Line Lost (IR Array)
```c
static uint32_t all_black_count = 0;

if (LineArray_IsAllBlack()) {
    if (++all_black_count >= 150) {   // 150 × 20ms = 3 seconds
        Vx = 0; Wz = 0;
        StateMachine_Transition(STATE_SAFE_STOP);
        // Initiate search: rotate ±15° alternating to re-acquire line
    }
} else {
    all_black_count = 0;
}
```
- **Trigger**: All 8 TCRT5000 sensors read LOW for more than 3 consecutive seconds
- **Response**: Stop forward motion → slow rotate search pattern → if line found, resume state; if not found after 10s, remain in SAFE_STOP
- **Prevention**: Temporal filter prevents transient bounces (small lift, debris) from triggering

### Low Battery
- **6.8V**: Flash status LED; reduce max gait speed by 30%
- **6.4V**: `Vx = 0, Wz = 0` → SAFE_STOP state → LED rapid blink

### I2C Bus Hang
```c
// If HAL_I2C_Master_Transmit returns HAL_TIMEOUT:
HAL_I2C_DeInit(&hi2c1);
HAL_Delay(10);
HAL_I2C_Init(&hi2c1);   // Re-initialise peripheral
```
- **Applies to**: I2C1 (PCA9685/MPU6050/TCS34725) and I2C2 (VL53L0X)
- **If I2C1 fails**: Servo commands cannot be sent → SAFE_STOP
- **If I2C2 fails**: ToF sensors unavailable → fall back to line-only navigation for Tasks 1 and 4; SAFE_STOP for Tasks 2 and 3 (require ToF)

### TCS34725 Colour Sensor Failure
- **Detection**: NACK on I2C1 read after 2 retries
- **Response**: Skip colour classification states (`TASK1_COLOR_ID`, `TASK4_JUNCTION_DETECT`)
- **Impact**: Partial run (cannot identify ball colour or select branch) — accept points for Task 1 navigation and Task 3 push

### Servo Stall / Overload
- **Detection**: IMU shows no positional change despite gait commands for >2 seconds
- **Response**: Reduce servo load → lower body height (shorter IK reach) → retry gait
- **Escalation**: If stall persists for >5s → SAFE_STOP

### Ball Pickup Timeout
- **Detection**: Gripper closes but robot has not transitioned from `TASK1_BALL_GRAB` within 10 seconds
- **Response**: Retry grab once (open gripper → reposition arm → close)
- **Escalation**: If second attempt fails → skip ball; continue circuit without ball; accept partial score

## 4. Flash Persistence — Ball Colour Recovery
A competition restart clears STM32 RAM but **not Flash**. The `stored_ball_color` variable is written to a dedicated Flash sector after Task 1 colour identification. On boot, the state machine reads this value:

```c
// On BOOT_INIT:
uint8_t recalled = Flash_ReadBallColor();
if (recalled != COLOR_UNKNOWN) {
    stored_ball_color = recalled;
    // If restarting at Task 4 checkpoint: skip directly to TASK4_LINE_FOLLOW
}
```

This allows the team to restart at the Task 4 checkpoint (if allowed by judges) without losing the ball colour memory.

## 5. Competition Restart Procedure
1. Press kill switch → all power off.
2. Team member may adjust sensor positions (line array height, TCS34725 angle) — no code changes allowed.
3. Press kill switch ON → STM32 boots (<500ms) → reads Flash colour.
4. Position robot at checkpoint → press start button → robot resumes from saved state.

## 6. Arena Safety
- Robot must not damage arena walls or floor lines.
- Crawl gait limits peak leg force.
- Passive bumper (no sharp edges) for obstacle pushing.
- All cables secured inside chassis to prevent trailing marks on floor.

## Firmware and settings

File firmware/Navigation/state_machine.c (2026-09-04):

/**
 * @file    state_machine.c
 * @brief   Mission HFSM Implementation — all 4 competition subtasks
 * @note    Call StateMachine_Update() every 20ms from main loop.
 *          All motion commands written to sm_Vx, sm_Vy, sm_Wz, sm_arm_position,
 *          sm_gripper, sm_gate — consumed by gait generator.
 */

#include "state_machine.h"
#include "line_follower.h"
#include <string.h>
#include <stdio.h>   /* printf for debug UART — remove in final build */

/* ─── Motion Command Globals ─────────────────────────────────────────────── */
float   sm_Vx           = 0.0f;
float   sm_Vy           = 0.0f;
float   sm_Wz           = 0.0f;
uint8_t sm_arm_position = ARM_HOME;
uint8_t sm_gripper      = GRIPPER_OPEN;
uint8_t sm_gate         = GATE_LOCKED;

/* ─── Private State ──────────────────────────────────────────────────────── */
static MissionState_t   current_state     = STATE_BOOT_INIT;
static ColorID_t        stored_ball_color = COLOR_UNKNOWN;
static uint32_t         state_timer_ms    = 0;  /* Time in current state (ms) */
static uint8_t          color_stable_cnt  = 0;  /* Consecutive stable colour reads */
static LineFollower_t   line_pd;

/* ─── Flash helpers ──────────────────────────────────────────────────────── */
static void _SaveColorToFlash(ColorID_t color) {
    HAL_FLASH_Unlock();
    FLASH_EraseInitTypeDef erase = {
        .TypeErase    = FLASH_TYPEERASE_SECTORS,
        .Sector       = BALL_COLOR_FLASH_SECTOR,
        .NbSectors    = 1,
        .VoltageRange = FLASH_VOLTAGE_RANGE_3
    };
    uint32_t err;
    HAL_FLASHEx_Erase(&erase, &err);
    HAL_FLASH_Program(FLASH_TYPEPROGRAM_BYTE, BALL_COLOR_FLASH_ADDR, (uint8_t)color);
    HAL_FLASH_Lock();
}

static ColorID_t _ReadColorFromFlash(void) {
    uint8_t val = *(volatile uint8_t*)BALL_COLOR_FLASH_ADDR;
    if (val == 0xFF || val > COLOR_BLUE) return COLOR_UNKNOWN;  /* erased / invalid */
    return (ColorID_t)val;
}

/* ─── Public API ─────────────────────────────────────────────────────────── */

void StateMachine_Init(void) {
    LineFollower_Init(&line_pd, LINE_FOLLOWER_KP, LINE_FOLLOWER_KD, LINE_FOLLOWER_WZ_MAX);
    stored_ball_color = _ReadColorFromFlash();
    current_state     = STATE_BOOT_INIT;
    state_timer_ms    = 0;

#ifdef DEBUG_UART_ENABLED
    printf("[SM] Init. Recalled ball colour: %d\r\n", (int)stored_ball_color);
#endif
}

void StateMachine_Transition(MissionState_t new_state) {
#ifdef DEBUG_UART_ENABLED
    printf("[SM] %d -> %d\r\n", (int)current_state, (int)new_state);
#endif
    current_state  = new_state;
    state_timer_ms = 0;
    color_stable_cnt = 0;
    LineFollower_Reset(&line_pd);
}

MissionState_t StateMachine_GetState(void)       { return current_state; }
ColorID_t      StateMachine_GetStoredColor(void) { return stored_ball_color; }

void StateMachine_SaveBallColor(ColorID_t color) {
    stored_ball_color = color;
    _SaveColorToFlash(color);
}

/* ─── Main Update (call every 20ms) ──────────────────────────────────────── */
void StateMachine_Update(const SM_SensorData_t *s) {
    state_timer_ms += 20;  /* Increment 20ms per call */

    switch (current_state) {

    /* ── BOOT & CALIB ─────────────────────────────────────────────────────── */
    case STATE_BOOT_INIT:
        sm_Vx = 0; sm_Vy = 0; sm_Wz = 0;
        /* Peripherals initialised in main() before this is called */
        StateMachine_Transition(STATE_SENSOR_CALIB);
        break;

    case STATE_SENSOR_CALIB:
        /* Sensor calibration runs passively — just wait */
        sm_Vx = 0; sm_Wz = 0;
        if (state_timer_ms >= 500) {
            StateMachine_Transition(STATE_IDLE_WAIT_START);
        }
        break;

    case STATE_IDLE_WAIT_START:
        sm_Vx = 0; sm_Wz = 0;
        /* Start condition: start button pressed (PA0 checked externally;
           call StateMachine_Transition(STATE_TASK1_LINE_FOLLOW) from main) */
        break;

    /* ── TASK 1: GRID SEARCH ─────────────────────────────────────────────── */
    case STATE_TASK1_LINE_FOLLOW:
        sm_Wz = LineFollower_ComputeOmega(&line_pd, s->line_centroid, 0.02f);
        sm_Vx = 60.0f;
        sm_arm_position = ARM_HOME;

        if (s->intersection) {
            if (s->tof_front_mm < 80) {
                StateMachine_Transition(STATE_TASK1_BALL_APPROACH);
            }
            /* If no ball at this intersection: continue line follow */
        }

        /* Line lost safety */
        if (LineArray_GetLostCycles(s->line_bits) >= LINEARRAY_LOST_TIMEOUT_CYCLES) {
            StateMachine_Transition(STATE_SAFE_STOP);
        }
        break;

    case STATE_TASK1_BALL_APPROACH:
        sm_Vx = 0; sm_Wz = 0;
        sm_arm_position = ARM_MODE_A;  /* Lower arm to ball level */
        if (state_timer_ms >= 800) {   /* 800ms for servo to reach position */
            StateMachine_Transition(STATE_TASK1_COLOR_ID);
        }
        break;

    case STATE_TASK1_COLOR_ID:
        sm_Vx = 0; sm_Wz = 0;
        sm_arm_position = ARM_MODE_A;

        if (s->last_color != COLOR_UNKNOWN) {
            color_stable_cnt++;
            if (color_stable_cnt >= 3) {
                StateMachine_SaveBallColor(s->last_color);
                StateMachine_Transition(STATE_TASK1_BALL_GRAB);
            }
        } else {
            color_stable_cnt = 0;
        }

        if (state_timer_ms >= 10000) {
            /* No colour detected after 10s — false alarm, resume grid */
            StateMachine_Transition(STATE_TASK1_LINE_FOLLOW);
        }
        break;

    case STATE_TASK1_BALL_GRAB:
        sm_Vx = 0; sm_Wz = 0;
        sm_arm_position = ARM_MODE_A;
        sm_gripper = GRIPPER_CLOSE;
        if (state_timer_ms >= 1200) {
            StateMachine_Transition(STATE_TASK1_STORE);
        }
        break;

    case STATE_TASK1_STORE:
        sm_Vx = 0; sm_Wz = 0;
        sm_gripper = GRIPPER_CLOSE;
        sm_arm_position = ARM_HOME;
        sm_gate = GATE_LOCKED;
        if (state_timer_ms >= 1000) {
            StateMachine_Transition(STATE_TASK1_GRID_EXIT);
        }
        break;

    case STATE_TASK1_GRID_EXIT:
        sm_Wz = LineFollower_ComputeOmega(&line_pd, s->line_centroid, 0.02f);
        sm_Vx = 60.0f;
        /* Transition condition: line lost (left grid) OR specific exit intersection */
        if (LineArray_IsAllBlack(s->line_bits) && state_timer_ms >= 500) {
            StateMachine_Transition(STATE_TASK2_WALL_FOLLOW);
        }
        break;

    /* ── TASK 2: CURVED CORRIDOR ──────────────────────────────────────────── */
    case STATE_TASK2_WALL_FOLLOW: {
        /* Wall PD centering: target = 150mm from each wall */
        float wall_error = (float)s->tof_left_mm - (float)s->tof_right_mm;
        sm_Wz = wall_error * 0.003f;    /* Tune this gain */
        sm_Vx = 80.0f;
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

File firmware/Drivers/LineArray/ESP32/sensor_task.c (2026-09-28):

/**
 * @file    sensor_task.c
 * @brief   FreeRTOS task: 100Hz line array update, UART stream to STM32
 *
 * Project: FusionForce RUNNER-4 | EN2533 BREACH PROTOCOL
 *
 * UART packet format (to STM32 at 115200 baud, 100Hz):
 *   '$'LA,<err_x100>,<active>,<junc>,<lost>,<crc8>\r\n
 *
 *   err_x100  : int16, error*100  (e.g. -1.25 -> -125, line lost -> -32768)
 *   active    : int, sensors above threshold (0-9)
 *   junc      : 0 or 1
 *   lost      : 0 or 1
 *   crc8      : CRC-8/MAXIM of all chars after '$' up to (not including) the ','crc field
 *
 * Calibration mode (at power-on):
 *   Hold BOOT button (GPIO0) for 3 seconds -> enters calibration routine
 */

#include "sensor_task.h"
#include "line_array_esp32.h"

#include <stdio.h>
#include <string.h>
#include <math.h>
#include <stdint.h>

#include "freertos/FreeRTOS.h"
#include "freertos/task.h"
#include "driver/uart.h"
#include "driver/gpio.h"
#include "nvs_flash.h"
#include "esp_log.h"

static const char *TAG = "SensorTask";

/* UART configuration */
#define ST_UART_PORT    UART_NUM_1
#define ST_UART_TX      17      /* GPIO17 -> STM32 RX */
#define ST_UART_RX      16      /* GPIO16 <- STM32 TX */
#define ST_UART_BAUD    115200

/* Task configuration */
#define ST_RATE_HZ      100
#define ST_PERIOD_MS    (1000 / ST_RATE_HZ)   /* 10ms */
#define ST_DBG_EVERY    20                     /* debug print at 5Hz */

/* Calibration button */
#define CAL_BTN_GPIO    0       /* BOOT button, active LOW */
#define CAL_HOLD_MS     3000

/* CRC-8/MAXIM polynomial 0x07 */
static uint8_t crc8_calc(const uint8_t *d, int len) {
    uint8_t crc = 0xFF;
    while (len--) {
        crc ^= *d++;
        for (int i = 0; i < 8; i++)
            crc = (crc & 0x80) ? ((crc << 1) ^ 0x07) : (crc << 1);
    }
    return crc;
}

static void uart_init(void) {
    const uart_config_t cfg = {
        .baud_rate  = ST_UART_BAUD,
        .data_bits  = UART_DATA_8_BITS,
        .parity     = UART_PARITY_DISABLE,
        .stop_bits  = UART_STOP_BITS_1,
        .flow_ctrl  = UART_HW_FLOWCTRL_DISABLE,
        .source_clk = UART_SCLK_APB,
    };
    uart_driver_install(ST_UART_PORT, 256, 256, 0, NULL, 0);
    uart_param_config(ST_UART_PORT, &cfg);
    uart_set_pin(ST_UART_PORT, ST_UART_TX, ST_UART_RX, UART_PIN_NO_CHANGE, UART_PIN_NO_CHANGE);
    ESP_LOGI(TAG, "UART1 init: %d baud, TX=GPIO%d, RX=GPIO%d", ST_UART_BAUD, ST_UART_TX, ST_UART_RX);
}

/* Check BOOT button at startup -- returns true if held for CAL_HOLD_MS */
bool sensor_task_check_calibration_request(void) {
    gpio_set_direction(CAL_BTN_GPIO, GPIO_MODE_INPUT);
    gpio_set_pull_mode(CAL_BTN_GPIO, GPIO_PULLUP_ONLY);
    if (gpio_get_level(CAL_BTN_GPIO) == 0) {
        ESP_LOGI(TAG, "BOOT held -- calibration in %dms...", CAL_HOLD_MS);
        vTaskDelay(pdMS_TO_TICKS(CAL_HOLD_MS));
        if (gpio_get_level(CAL_BTN_GPIO) == 0) return true;
    }
    return false;
}

/* Full calibration routine (blocking) */
void sensor_task_run_calibration(void) {
    LA_Init();
    ESP_LOGI(TAG, "=== CALIBRATION MODE ===");
    ESP_LOGI(TAG, "Place ALL sensors over WHITE. Waiting 3s...");
    vTaskDelay(pdMS_TO_TICKS(3000));
    ESP_LOGI(TAG, "Sampling white...");
    LA_Calibrate(true);
    ESP_LOGI(TAG, "Done. Place ALL sensors over BLACK. Waiting 3s...");
    vTaskDelay(pdMS_TO_TICKS(3000));
    ESP_LOGI(TAG, "Sampling black...");
    LA_Calibrate(false);

    LA_Calibration_t cal;
    LA_GetCalibration(&cal);
    for (int i = 0; i < LA_NUM_SENSORS; i++)
        ESP_LOGI(TAG, "S%d: white=%d black=%d range=%d", i+1, cal.min_val[i], cal.max_val[i], cal.max_val[i]-cal.min_val[i]);

    ESP_LOGI(TAG, "Calibration DONE. Reboot for normal operation.");
    gpio_set_direction(2, GPIO_MODE_OUTPUT);
    while (1) {
        gpio_set_level(2, 1); vTaskDelay(pdMS_TO_TICKS(200));
        gpio_set_level(2, 0); vTaskDelay(pdMS_TO_TICKS(200));
    }
}

/* Main 100Hz sensor task */
void sensor_task(void *arg) {
    ESP_LOGI(TAG, "Sensor task started (%d Hz)", ST_RATE_HZ);
    uart_init();

    if (LA_Init() != ESP_OK) {
        ESP_LOGE(TAG, "LA_Init failed -- task abort");
        vTaskDelete(NULL); return;
    }

    LA_Result_t res;
    int dbg = 0;
    TickType_t wake = xTaskGetTickCount();

    while (1) {
        /* ---- Read & process sensors ------------------------------------ */
        LA_Update(&res);

        /* ---- Build UART packet ----------------------------------------- */
        /* Format: ,err_x100,active,junc,lost,CRC\r\n */
        char body[48];
        int16_t err_enc = isnan(res.error) ? INT16_MIN : (int16_t)(res.error * 100.0f);
        int body_len = snprintf(body, sizeof(body), "LA,%d,%d,%d,%d",
                                err_enc, res.active_count,
                                res.is_junction ? 1 : 0,
                                res.is_line_lost ? 1 : 0);

        uint8_t crc = crc8_calc((uint8_t*)body, body_len);

        char pkt[64];
        int pkt_len = snprintf(pkt, sizeof(pkt), "$%s,%02X\r\n", body, crc);
        uart_write_bytes(ST_UART_PORT, pkt, pkt_len);

        /* ---- Debug print at 5Hz --------------------------------------- */
        if (++dbg >= ST_DBG_EVERY) { LA_PrintDebug(&res); dbg = 0; }

        /* ---- Maintain precise 10ms period ----------------------------- */
        vTaskDelayUntil(&wake, pdMS_TO_TICKS(ST_PERIOD_MS));
    }
}

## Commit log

2026-07-23 Update servo count options in hardware plan
2026-08-10 3d leg designs
    [Assem1.SLDASM, Base Down.SLDPRT, Base up.SLDPRT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]
2026-09-08 servo controller 01
2026-09-28 motor controller
2026-09-30 Add ESP32 IR line array test sketch for TCRT5000 calibration and line-follow logic
2026-10-03 update walking stage
2026-10-04 Modify sensor pin configuration and comments
    Updated sensor pin order and clarified white line detection.
2026-10-07 color sensor finish
2026-10-08 Add files via upload
    separate codes for each sensors
2026-10-16 fix power issue
2026-10-16 Get the angle chnage in to one variable and corrected stages code
2026-10-17 one leg lift code
2026-10-17 Add files via upload
    code for the Arm part
